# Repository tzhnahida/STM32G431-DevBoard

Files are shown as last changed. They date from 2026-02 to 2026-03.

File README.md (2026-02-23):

# STM32G431 Development Board (v1.0)

## Overview
This is a high-performance development platform based on the **STM32G431Vx** microcontroller (ARM® Cortex®-M4 with FPU). The board is engineered for advanced power electronics and motion control applications, integrating high-speed communication interfaces, precision power monitoring, and wireless connectivity.

## Key Hardware Features

### 1. Processing Core
* **MCU**: STM32G431Vx, 32-bit ARM® Cortex®-M4 with FPU, high-performance analog peripherals, and mathematical accelerators (CORDIC/FMAC).
* **Clocking**: 8MHz High-Speed External (HSE) crystal and 32.768kHz Low-Speed External (LSE) crystal for RTC.

### 2. Power Management
* **Dual Power Domains**: 
    * **Logic Power**: 5V input via USB Type-C, converted to 3.3V via **TLV62569** (DC-DC) for high efficiency.
    * **Analog Power**: Dedicated **LP5907** ultra-low noise LDO for VDDA and audio precision.
* **Motor Power (MVCC)**: High-voltage input via XT30 connectors with **SMCJ33A** TVS protection for regenerative braking spikes.

### 3. Integrated Peripheral Modules
* **Motor Driving**: 
    * 4x **A4950** Full-Bridge Motor Drivers for DC motor control.
    * Integrated current and voltage monitoring via 4x **INA226** (I2C) high-side monitors.
* **Wireless Connectivity**: Onboard **ESP32-C6** module supporting Wi-Fi 6, Bluetooth 5 (LE), Zigbee, and Thread.
* **Audio System**:
    * **PCM5102A** High-resolution Audio DAC with 3.5mm Jack output.
    * **ICS-43434** Digital I2S MEMS Microphone.
* **Communication**:
    * **TJA1044GT** Transceiver for FDCAN connectivity.
    * **CH340N** USB-to-UART bridge for debugging and firmware logging.
* **Storage**:
    * 64M-bit SPI Nor Flash (**W25Q64JV**).
    * 256K-bit I2C EEPROM (**AT24C256**).

### 4. User Interface
* **Display**: Dedicated SPI header for 1.77" LCD modules.
* **Interaction**: 4x Programmable User LEDs (Red) and 4x User Push-buttons (KEY1-KEY4).

## Peripheral Pin Mapping
| Component | Interface | Pin Assignment |
| :--- | :--- | :--- |
| **USB-Serial** | UART1 | TX: PA9, RX: PA10 |
| **ESP32-C6** | UART2 | TX: PA2, RX: PA3 |
| **CAN Bus** | FDCAN1 | TX: PD1, RX: PD0 |
| **Power Monitors** | I2C3 | SCL: PC8, SDA: PC9 |
| **Audio DAC/Mic** | I2S | SCK: PB3, WS: PA15, SD: PB5 |
| **External Flash** | SPI1 | SCK: PA5, MISO: PA6, MOSI: PA7 |

## Technical Specifications
* **Logic Voltage**: 3.3V DC
* **Motor Voltage Range**: Up to 30V DC (MVCC)
* **MCU Package**: LQFP-100
* **Communication Support**: FDCAN, Wi-Fi 6, BLE, Zigbee, SPI, I2C, I2S

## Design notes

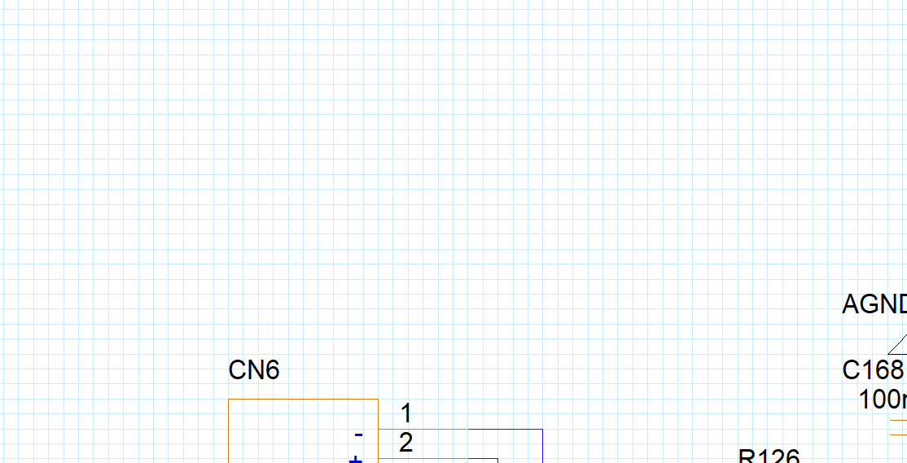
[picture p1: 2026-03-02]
STM32G431-DEVBOARD.png

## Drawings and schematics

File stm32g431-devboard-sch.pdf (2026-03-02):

Type-C Power IN | | F1 | 220R@100MHz FB1 | | 5V IN to 3V3 AC VCC_5V

# LDO

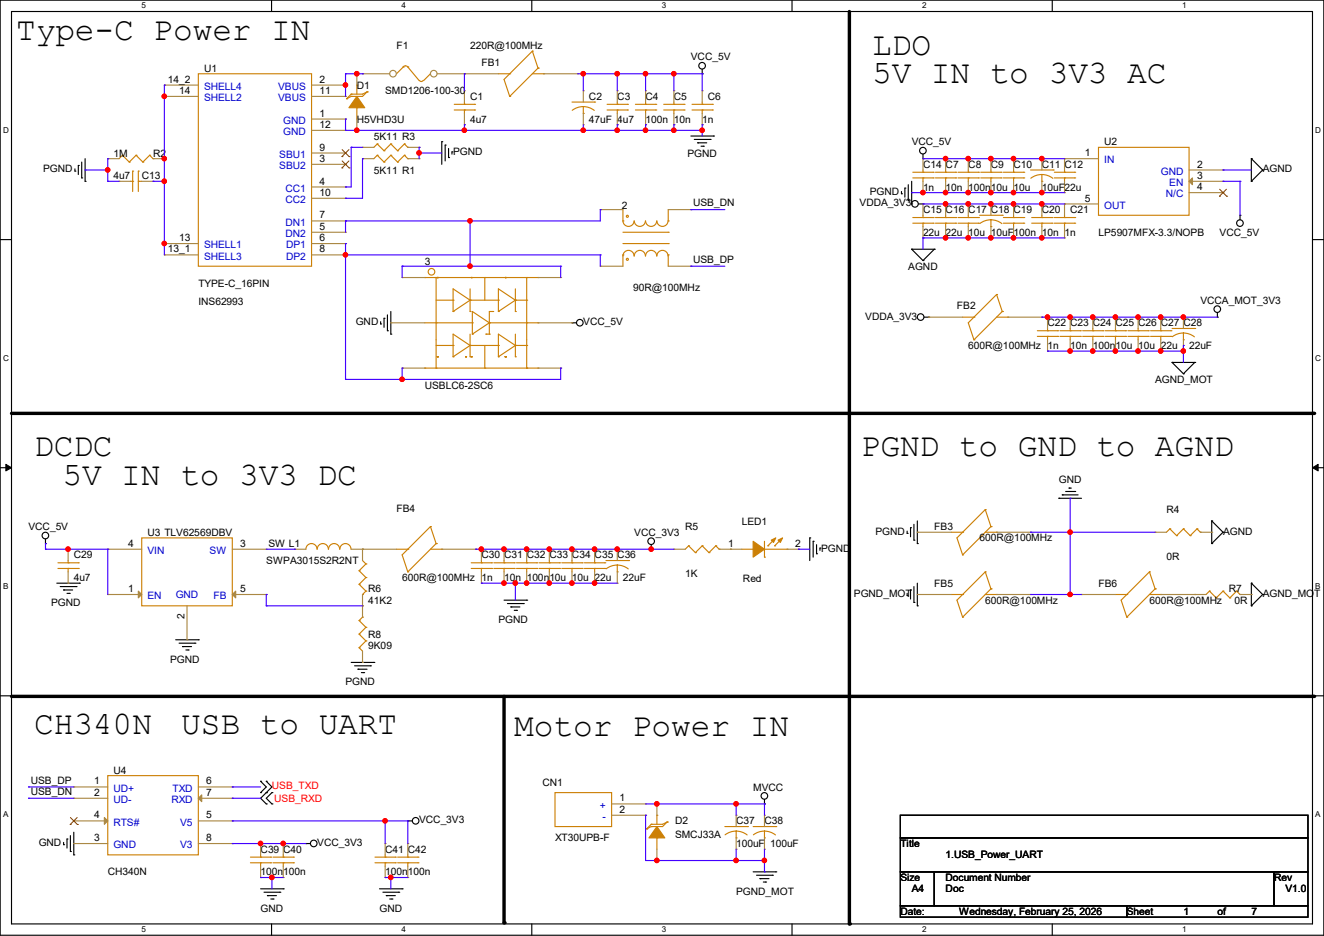
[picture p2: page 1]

PGND to GND to AGND

# OSC

MCU Power | NRTS | BOOT0

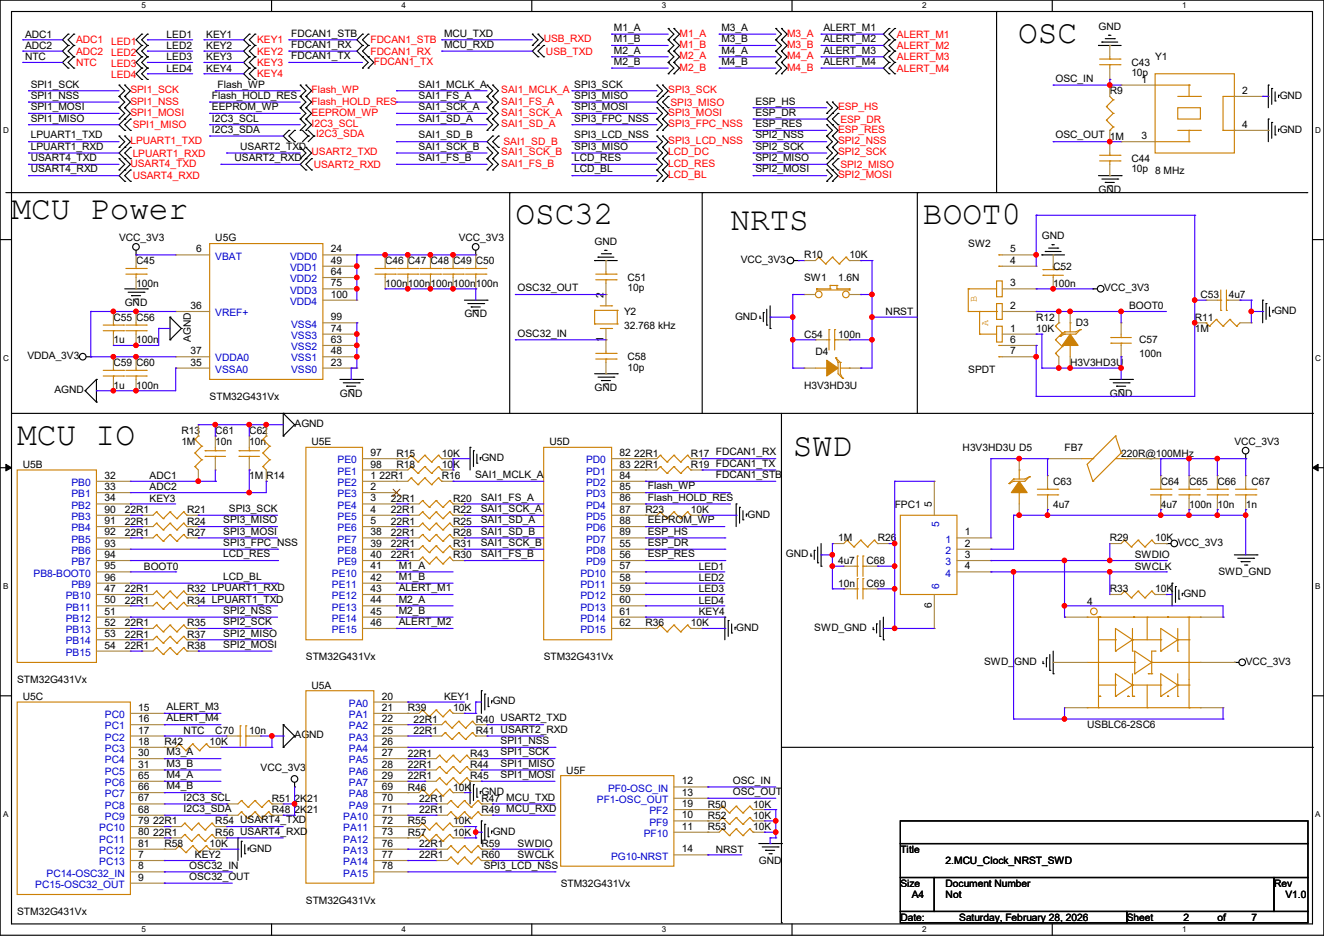
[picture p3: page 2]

FB7 220R@100MHz

# ADC

# LED

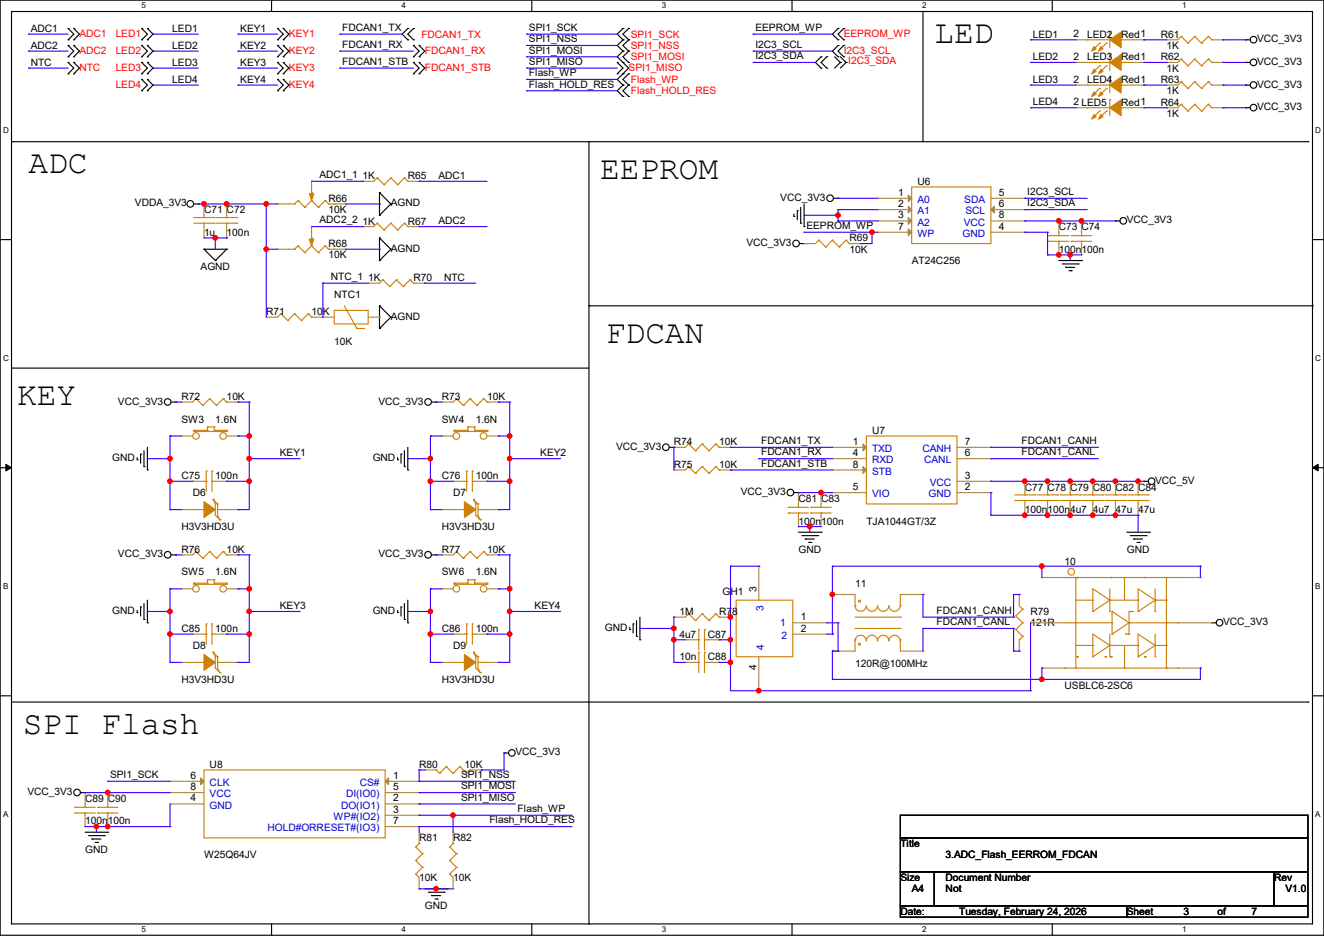
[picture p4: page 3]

# Audio

# UART

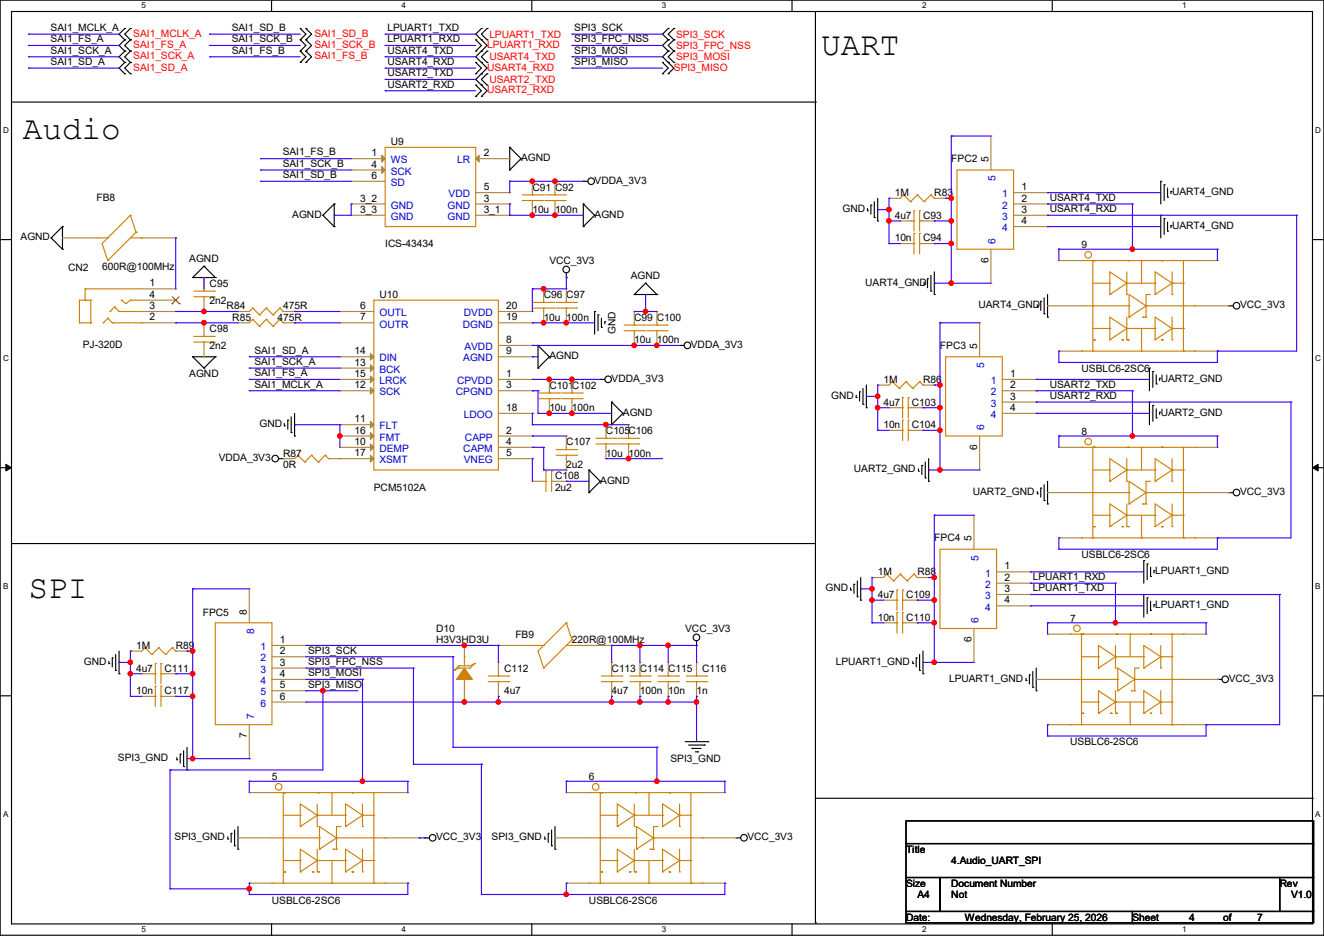
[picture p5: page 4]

# ESP_OSC

# ESP Flash

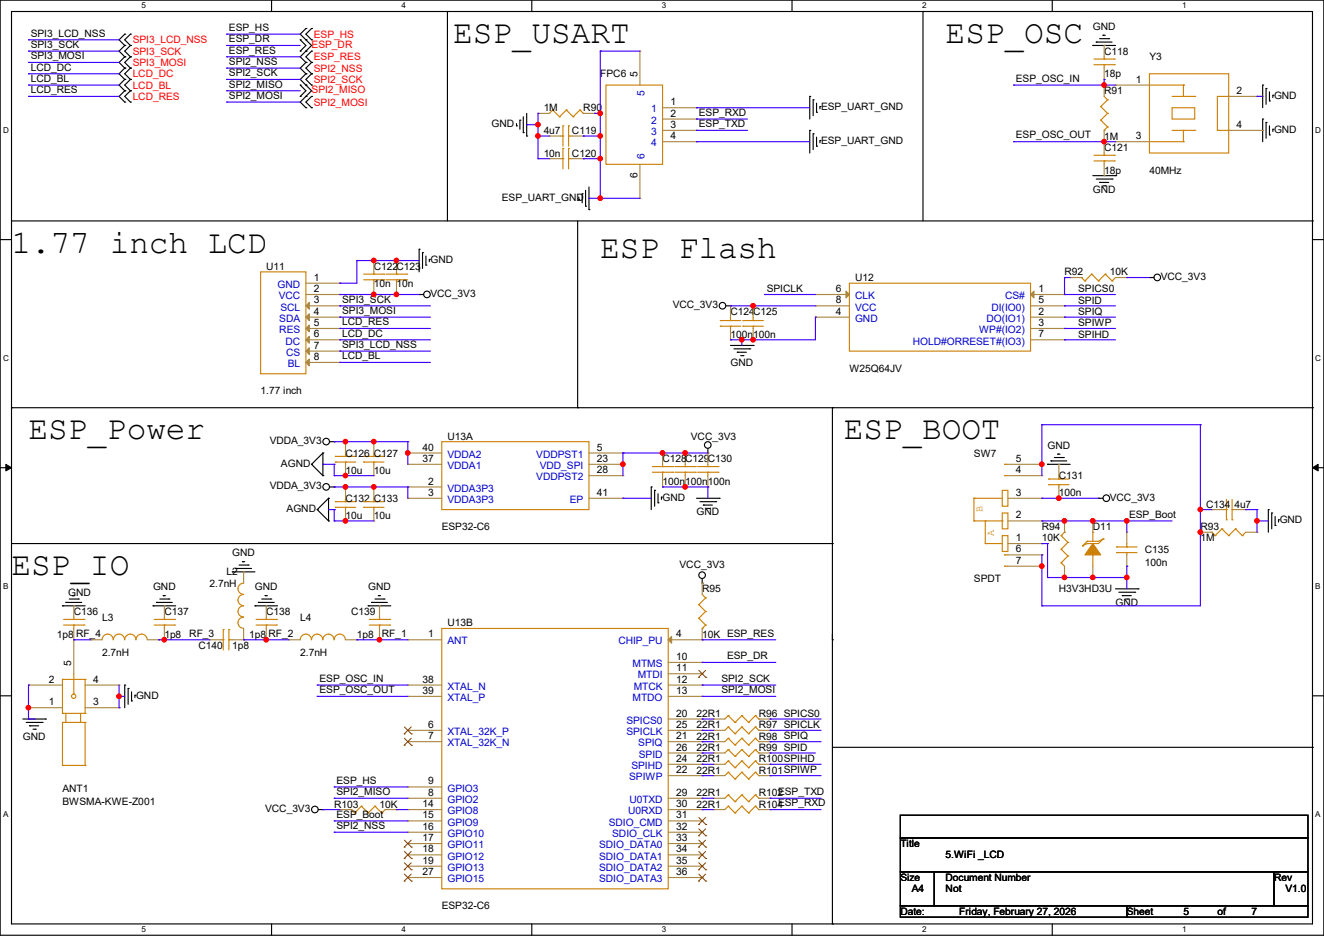
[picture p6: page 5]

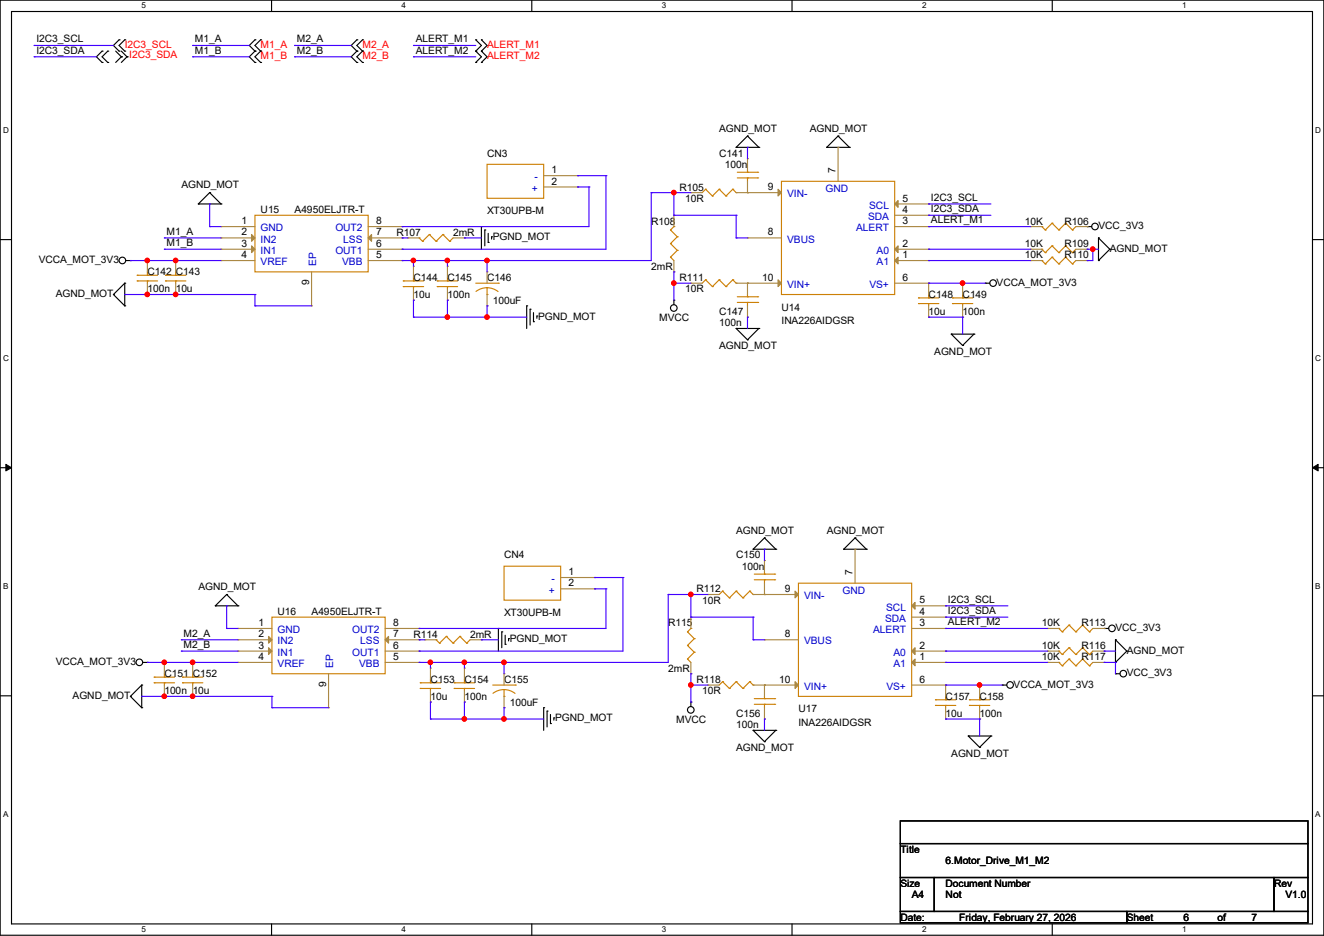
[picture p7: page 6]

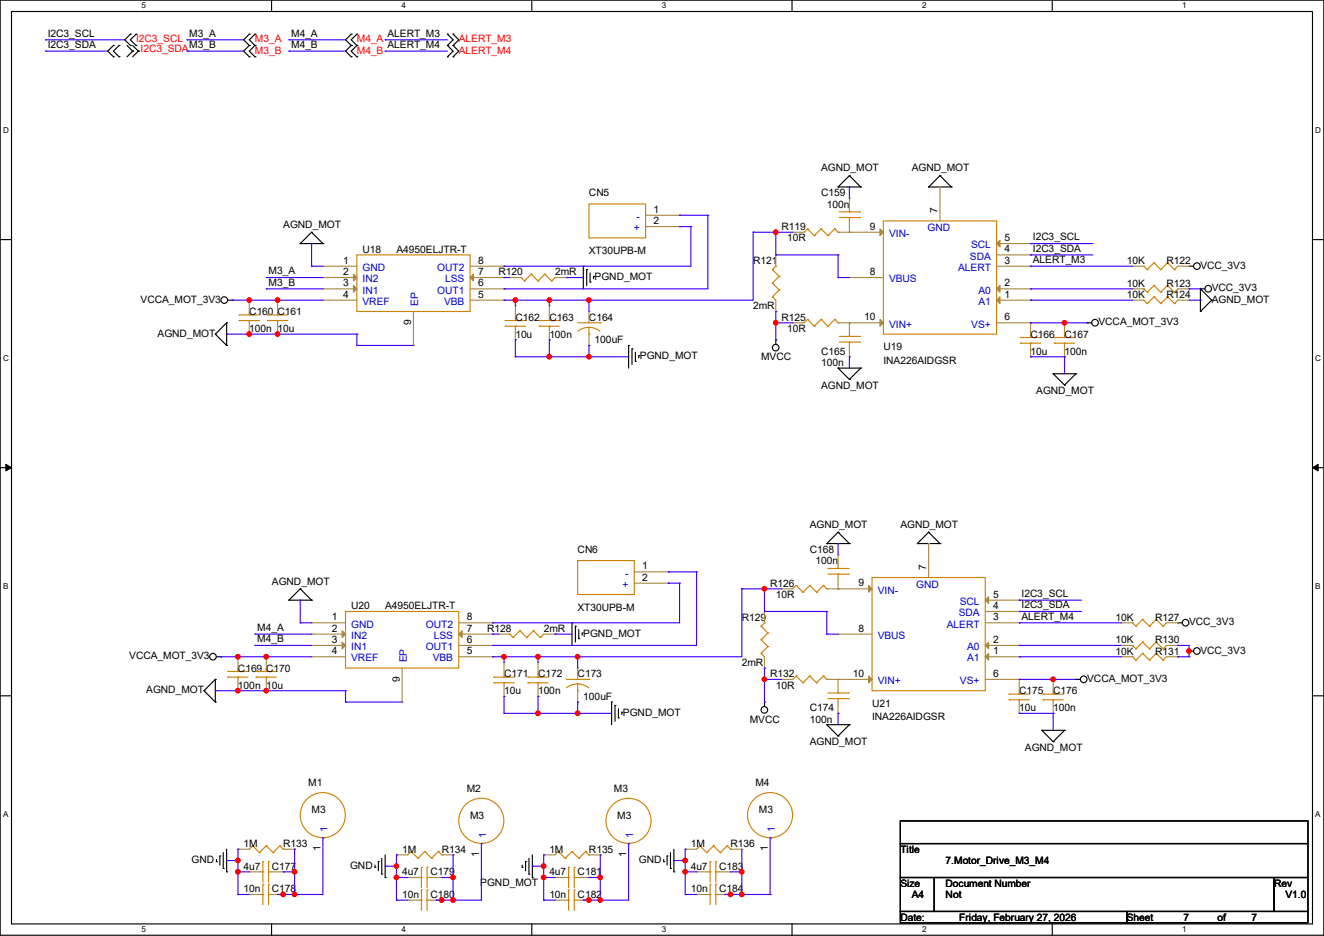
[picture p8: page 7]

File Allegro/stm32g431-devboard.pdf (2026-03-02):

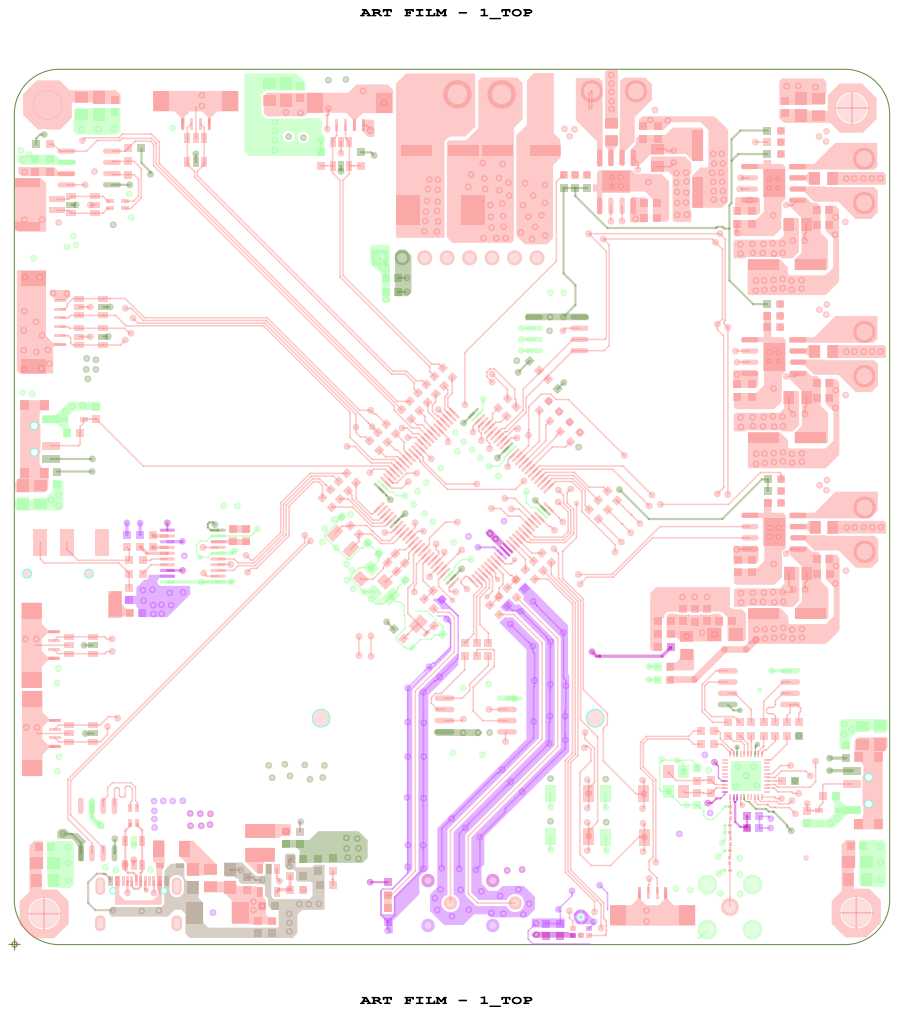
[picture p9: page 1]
ART FILM - 1_TOP

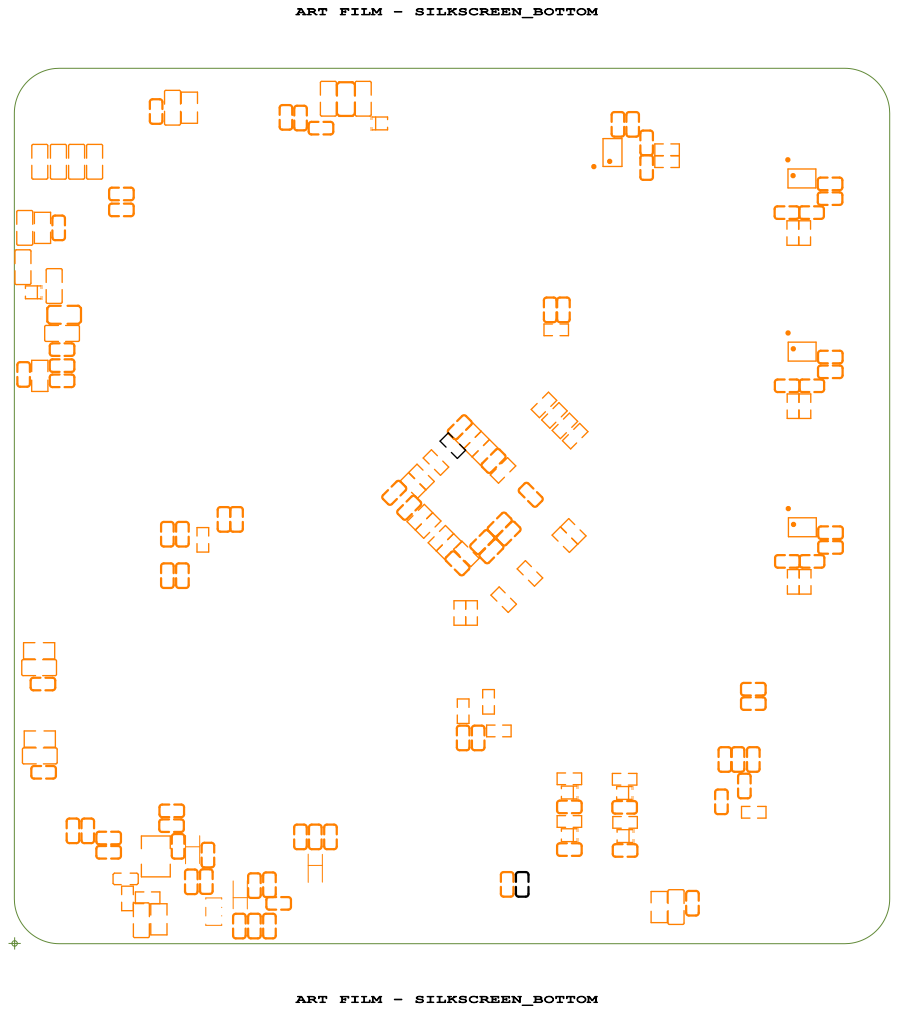
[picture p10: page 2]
ART FILM - SILKSCREEN_BOTTOM

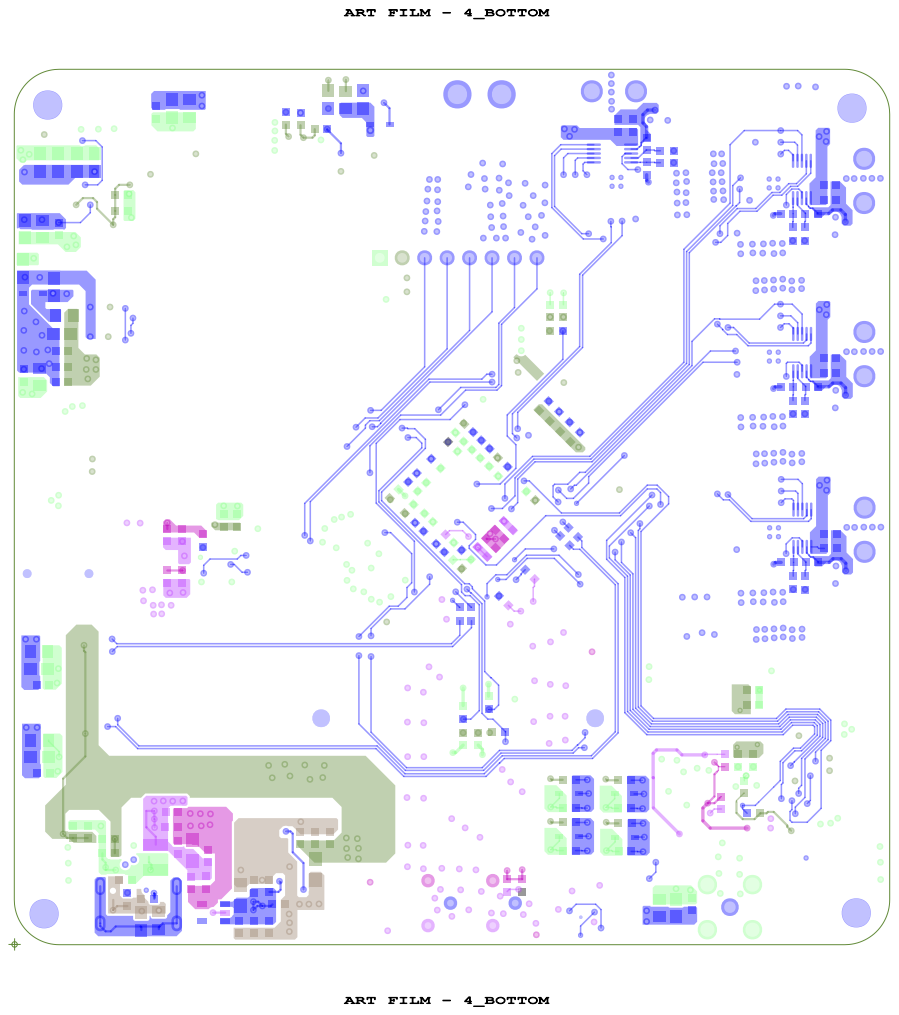
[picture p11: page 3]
ART FILM - 4_BOTTOM

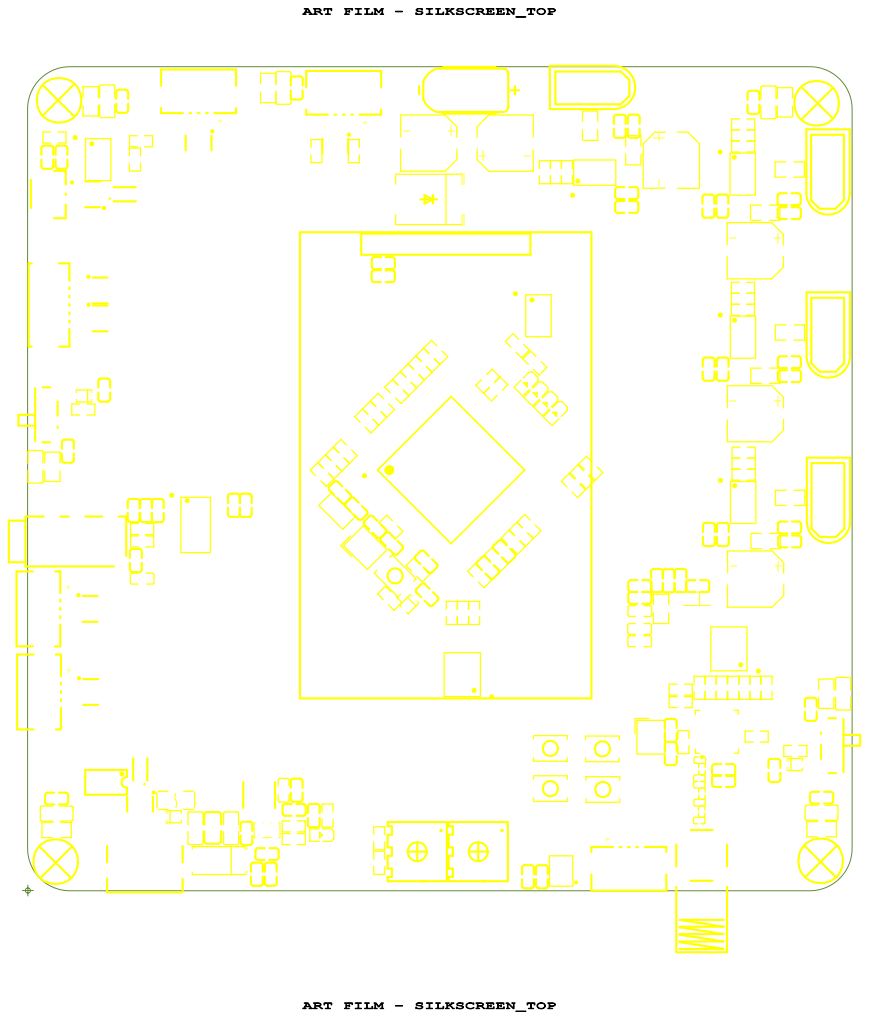
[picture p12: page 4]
ART FILM - SILKSCREEN_TOP

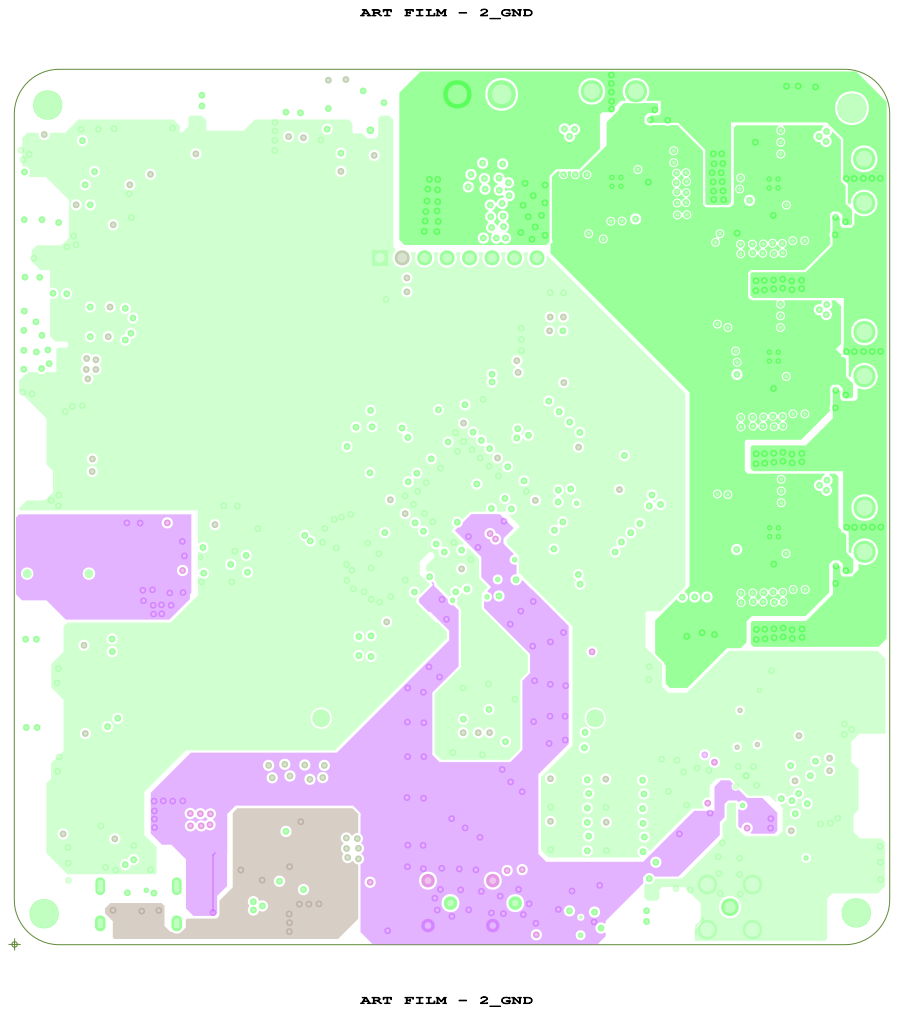
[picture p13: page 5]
ART FILM - 2_GND

ART FILM - 3_Power

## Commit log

2026-02-14 First submission
    [STM32G431-DEVBOARD.DSN]
2026-02-14 feat: initial commit of power protection module with TVS and EMI filtering
    [STM32G431-DEVBOARD-DRCS-Report.csv, STM32G431-DEVBOARD.DSN]
2026-02-15 feat: finalize power input protection and 3.3V DCDC regulation circuit
    [STM32G431-DEVBOARD.DSN]
2026-02-15 feat: complete USB-C interface, DCDC power, and CH340N circuit
    [STM32G431-DEVBOARD-DRCS-Report.csv, STM32G431-DEVBOARD.DSN]
2026-02-16 feat(hw): finalize STM32G431 core schematics and peripheral protection
    [STM32G431-DEVBOARD.DSN]
2026-02-18 feat: add SPI_Flash,I2C_EEPROM,FDCAN
    [STM32G431-DEVBOARD-DRCS-Report.csv, STM32G431-DEVBOARD.DSN]
2026-02-21 refactor: separate GND into GND, PGND, and AGND; add VDDA LDO and Audio/IO page
    - Refactor global ground network into segmented GND (digital), PGND (power), and AGND (analog) to improve noise isolation.
    - Add 5V to 3.3V LDO circuit specifically for VDDA_3V3 to provide low-noise power for analog peripherals.
    - Add Page 4: Audio_UART_SPI_FPC including:
    - PCM5102A Audio DAC and ICS-43434 MEMS Microphone.
    - Protected SPI3 interface with dual USBLC6-2SC6 ESD protection.
    - Multiple UART FPC connectors with RC soft-grounding.
    [STM32G431-DEVBOARD.DSN]
2026-02-23 The schematic diagram is complete. A new motor control circuit has been added, along with a dedicated analog power supply and analog ground for the motor circuit.
    [STM32G431-DEVBOARD.DSN]
2026-02-23 Create an Allegro project and complete the power supply layout and some wiring.
    [STM32G431-DEVBOARD.DSN, stm32g431-devboard.brd]
2026-02-24 Complete the small layout of each module and the wiring of some modules.
    [STM32G431-DEVBOARD.DSN, stm32g431-devboard.brd]
2026-02-26 Completed partial wiring
    [cases.cfg, stm32g431-devboard.brd]
2026-02-27 Complete wiring
    [STM32G431-DEVBOARD.DSN, cases.cfg, stm32g431-devboard.brd]
2026-03-02 Add copper pours to the top and bottom GND layers, add teardrop shapes, and smooth out the traces.
    [stm32g431-devboard.brd]
2026-03-02 Export Gerber
    [HL_VPN_bf.brd, cases.cfg, stm32g431-devboard.brd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]
